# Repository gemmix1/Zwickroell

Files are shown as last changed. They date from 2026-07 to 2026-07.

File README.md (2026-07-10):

# Messstand für Zugproben — Kontakt-Mikrometer (v5)

Autonomes Messgerät für flache **Zugproben (Dogbone, 166 × 20/12 × 6 mm)**:
misst **Dicke und Breite** berührend mit **einem** DC-Motor.

**Prinzip:** Motor + Encoder + T8-Spindel bilden eine Mikrometerschraube
(0,5 µm/Count). Ein federnder **Taststift** mit **Mikroschalter** tastet die
Probe von oben an; ein **Servo** dreht die Probe (0°/90°/180°), ein federnder
**Rastbolzen** definiert die Winkel exakt. Maße entstehen aus Encoder-Differenzen:
`Maß = |2C − (Z_a + Z_b)| · k` — zentrierungs-unempfindlich, einmalige
Endmaß-Kalibrierung. Genauigkeit: **±0,015–0,03 mm** Wiederholbarkeit,
eine Messung ≈ **40 s** (jede Seite 3× angetastet, Mittelwert).

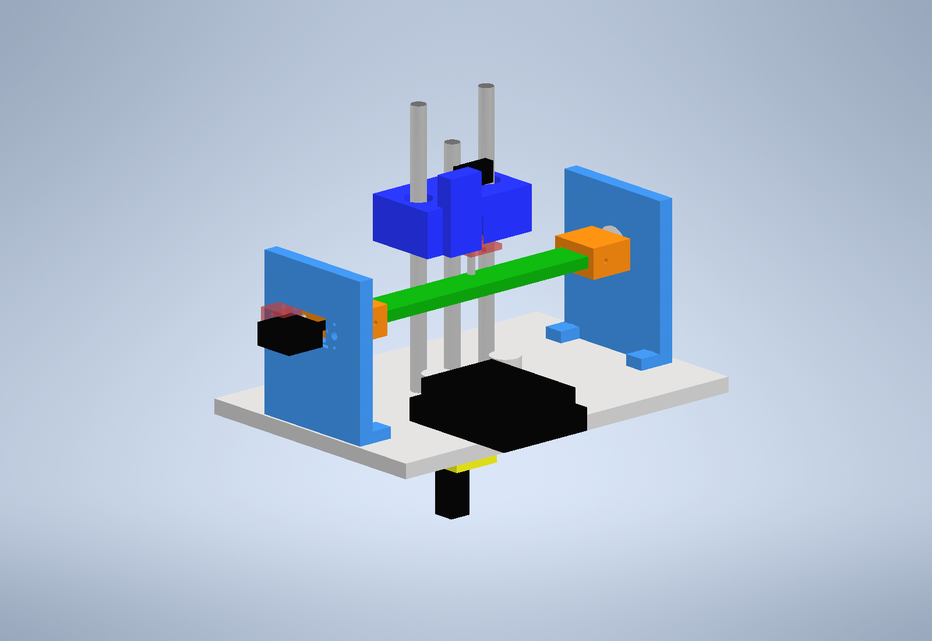
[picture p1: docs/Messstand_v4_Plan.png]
Baugruppe


## 📁 Struktur

| Ordner | Inhalt |
|---|---|
| `cad/` | Inventor-Quellen: **Messstand_v4.iam** (Gesamt-Baugruppe) + alle .ipt |
| `stl/` | **druckfertige STLs** (12 Teile) + Druck-/Montage-Anleitung |
| `gesliced/` | fertig gesliced für **Bambu Lab H2C** (.gcode.3mf, PETG, 0,2 mm) |
| `firmware/` | `messprogramm.ino` (Arduino Uno + Pololu MAX14870-Shield) |
| `scripts/` | PowerShell-Skripte, die alle Teile per Inventor-COM erzeugen |
| `scripts/archiv/` | Skripte früherer Versionen |
| `docs/` | Renderings der Baugruppe |
| `archiv/` | alte Teile/Konzepte (ToF-Variante v3, Sensorarm, …) |

**Anleitungen:** [Bausatz_Anleitung.md](Bausatz_Anleitung.md) (Bestellliste ~78 €,
Verkabelung, Montage, Kalibrierung) · [stl/00_ANLEITUNG.txt](stl/00_ANLEITUNG.txt)
(Druck-Orientierung, Zusammenbau) · [Projektverlauf.md](Projektverlauf.md)
(alle Entscheidungen chronologisch).

## 🔌 Verkabelung (Kurzfassung)

```
Pololu Dual MAX14870 Shield auf Arduino Uno
  M1A/M1B  -> Motor (Waveshare N20 12V 1:150, MIT Encoder!)
  VIN/GND  -> 12 V
Encoder A/B -> Pin 2/3   |  Mikroschalter -> A0/GND
Servo SG90  -> Pin 6     |  (Shield belegt 4,7,8,9,10,12)
```

## ⚙️ Inbetriebnahme

1. `STEIGUNG` in der Firmware an die Spindel anpassen (T8x2 → 2.0) —
   Prüftest: 10 Umdrehungen = 20 mm Weg.
2. `s` — Servo-Positionen justieren, bis der Rastbolzen sauber einrastet.
3. `k` — Dicke kalibrieren (Endmaß bekannter Dicke einspannen).
4. `w` — Breite kalibrieren (Endmaß bekannter Breite, Klemmschrauben angezogen).
5. `m` — messen. `1`–`9` wählt die Zahl der Durchläufe (Standard 1 ≈ 40 s,
   `3` ≈ 2 min für ±15 µm).

## 🖨 Drucken

Alles in `stl/` je 1× (Fensterdeckel 2×), PETG/PLA+, 0,2 mm, 4 Wände, 40 % Infill.
Für den **Bambu Lab H2C** liegen in `gesliced/` fertige Platten
(`Alles_Eine_Platte.gcode.3mf` = alle 13 Teile, ~7,2 h, 331 g — einfach per
USB-Stick an den Drucker). Teile neu erzeugen: `scripts\build_v4b_teile.ps1`
(braucht Autodesk Inventor).

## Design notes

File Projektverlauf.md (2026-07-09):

# Projektverlauf — Messstand für Zugproben

Chronologische Doku der Entscheidungen und Dateien. Stand: 2026-06-16.

## Ziel
Ein Messstand, der eine **flache Zugprobe (Dogbone, 166 × 20/12 × 6 mm)** fest
einspannt und mit einem **Distanzsensor** zwei Maße erfasst: **Breite** und **Dicke**.
Bewegung über **Motor + Encoder + Gewindestangen**, so genau wie möglich.

## Verlauf / Entscheidungen
1. **Motor:** Yunir 1218-N20 (12 V, 27 U/min) — laut Amazon „mit Encoder", real aber
   nur 2 Anschlüsse → **kein Encoder**. Empfehlung: N20 **mit echtem 6-Pin-Encoder**
   (Waveshare, 7 PPR) → mit 4× Quadratur + Getriebe hohe Auflösung.
2. **Antrieb:** Motortreiber **Pololu Dual MAX14870 Shield** (vorhanden).
3. **Lineartechnik:** statt M8-Gewindestange präzisere **T8-Spindel + Anti-Backlash-Mutter**
   empfohlen (Spindelspiel ist der Genauigkeits-Flaschenhals). Reale Vorrichtung nutzt
   nun **2 M8-Gewindestangen als 2 Achsen**.
4. **Messprinzip:** ToF (VL53L1X) ist für 6 mm/12 mm grenzwertig genau (±1 mm). Echte
   Genauigkeit kommt über **Encoder-Position beim Querscan** (Kantenerkennung) bzw.
   einen Laser-Triangulationssensor. Aktuell: Konzept A — **ein Querscan** liefert
   Breite (Kanten) + Dicke (Höhenstufe), 2-Achs-Aufbau für beide Maße.
5. **Einspannung:** Dogbone-Mulde lokalisiert die Probe; **offenes Mess-Fenster** unter
   dem Messbereich erzeugt scharfe ToF-Kanten.

## Dateien
**Mechanik (3D-Druck):**
- `Grundplatte_v2.ipt/.stl` — Platte mit Dogbone-Mulde + ToF-Fenster + Klemmlöcher
- `Sensorarm.ipt/.stl` — M8-angetrieben, abnehmbare Sensorhalterung
- `wellenkupplung_3mm_8mm.ipt/.stl` — Motor (3 mm) ↔ Spindel (8 mm)
- `Gewindestange_M8.ipt`, `Motor_N20.ipt`, `Stuetze.ipt`, `Sensor_VL53L1X.ipt` — Repräsentationsteile
- `Messstand_Komplett.iam` — **Gesamt-Baugruppe** (Positionen sind ein Konzept-Layout, anpassbar)

**Steuerung:**
- `linearantrieb.ino` — Motor + Encoder + ToF (Motor läuft bei Distanz < Schwelle, stoppt sofort)

**Build-Skripte (parametrisch, erzeugen die Teile neu):**
- `build_grundplatte_v2.ps1`, `build_sensorarm.ps1`, `build_kupplung_stl.ps1`,
  `build_einzelteile.ps1`, `build_baugruppe.ps1`
- Inspektions-/Render-Skripte liegen im Ordner `inspect\`

**Eingaben des Nutzers (nicht verändert):** `Grundfläche Neu.ipt`, `12x6_Probestück.ipt`

## Ein-Motor-Ausbau (2026-07-01)
Festgelegt: **nur EIN Motor**, ein einziger Querscan misst Breite UND Dicke.
- `Grundplatte_v3.ipt/.stl` (via `build_grundplatte_v3.ps1`): schmales Fenster
  (scharfe Kanten) + **Referenz-Boss (+5 mm)** neben der Probe für Live-2-Punkt-
  Kalibrierung des ToF. Profil im Scan: Platte(0) | Fenster | Probe | Fenster | Boss(+5).
- `messprogramm/messprogramm.ino` komplett auf Genauigkeit neu geschrieben:
  unidirektionaler Scan (kein Umkehrspiel), interpolierte Kanten (Breite),
  statische 3-Plateau-Nachmessung mit 200 ms-Budget + 2-Punkt-Cal (Dicke),
  N Pässe mit Statistik, Backlash-Anfahrt von unten, EEPROM-Kalibrierung (`z`/`w`).
  Sensor korrekt auf **VL53L0X** (Pololu-Lib aus dem Zip) umgestellt.

## Richtungswechsel v4 — Kontakt-Mikrometer (2026-07-01)
Entscheidung: **berührungslos verworfen**, weil der ToF die Dicke prinzipiell auf
~±0,1 mm begrenzt. Stattdessen **Kontakt-Antastung nach Mikrometer-Prinzip** —
gleichzeitig genauer UND günstiger (Genauigkeit aus Encoder + Mechanik):
- DC-Motor + Encoder + M8-Spindel = Mikrometerschraube (0,298 µm/Count).
- Federgelagerter Taststift + **Mikroschalter** (Probe ist Kunststoff/Composite →
  kein elektrischer Kontakt) meldet Berührung; Encoder liest Position.
- **Servo dreht die Probe** (0/90/180/270°) → dieselbe Achse misst Dicke UND Breite.
- Messung zentrierungs-unempfindlich: `Maß = |2C − (Z_a+Z_b)|·k` (Summe zweier
  gegenüberliegender Antastungen; Drehachse fällt raus). 1× Endmaß-Kalibrierung (`k`).

Entschieden: **vorhandener SG90 (180°)** wird genutzt → `USE_270_SERVO 0`, Breite
über zentrierte Klemme. Wellenlänge 150 mm.

Erzeugt & verifiziert (Volumen-Check + Render):
- `Taster_Schlitten.ipt/.stl` (`build_taster_schlitten.ps1`) — läuft auf 2
  LM8UU-Führungsstangen, M8-Spindelmutter mittig, Taststift + D2F-Mikroschalter vorne.
- `Dreh_Klemme.ipt/.stl` (`build_dreh_klemme.ps1`) — Zentriertasche 20×6 auf der
  Drehachse, SG90-Ritzelaufnahme Ø4.8 + M2 axial, Ø44-Flansch mit 4 Index-Löchern
  (90°) für exakte Rechtwinkligkeit (Index-Pin vom Rahmen).
- `messprogramm.ino` — Kontakt-Mikrometer (Antast-Routine, Servo 0/90/180,
  2C-Kalibrierung im EEPROM).

### Einkaufsliste (Amazon, ~36 € < 50 €) — Servo vorhanden
| Teil | ca. € | Zweck |
|---|---:|---|
| 2× Linearwelle 8 mm glatt (150 mm) | 9 | Führung des Taster-Schlittens (glatt, nicht M8!) |
| 4× LM8UU Linearlager | 7 | Schlitten auf den Wellen |
| Mikroschalter D2F/Subminiatur (5er) | 6 | Kontaktmelder am Taststift |
| Druckfeder-Sortiment | 6 | Taststift-Vorspannung |
| M8-Messing-/POM-Mutter (Anti-Backlash) | 3 | Spindelmutter im Schlitten |
| Härtestift/Kugel 4 mm (Taststift) | 5 | verschleißfeste Tastspitze |
| **Summe** | **~36** | Servo (SG90) + M8-Stange schon vorhanden |

### Baugruppe & restliche Teile (2026-07-01)
Erzeugt: `Rahmen_v4` (Grundplatte + 2 Wellenaufnahmen bei x=−14/y=±22 + Spindelloch
x=−14 + Servo-Wand mit Index-Pin-Loch + Idler-Wand-Journal), `Idler_Klemme`
(Zentriertasche + Ø8-Zapfen), `Fuehrungswelle_8x150`, `Probe_Platzhalter`.
**`Messstand_v4.iam`** = Konzept-Layout aller Teile (Matrix-Platzierung, keine
Constraints) + `Messstand_v4_Konzept.png`. Spindel/Wellen bewusst um 14 mm in X
versetzt, damit die Spindel die Probe (x=0, längs Y) nicht durchdringt; Schlitten
90° gedreht, sodass der Taststift trotzdem über x=0/y=0 (Probenmitte) sitzt.

Druckteile (STL fertig): `Rahmen_v4`, `Taster_Schlitten`, `Dreh_Klemme`, `Idler_Klemme`.
Kaufteil/Referenz (nicht drucken): `Fuehrungswelle_8x150` (glatte Welle), `Probe_Platzhalter`.

## v4b — Design-Review & Komplettkorrektur (2026-07-03)
Systematische Prüfung vor dem Druck fand **schwere Fehler in v4**, alle behoben:
1. **Rahmen_v4 war unbrauchbar**: Wände schwebten 17 mm neben der Platte (Platte
   ±70, Wände bei ±91) → STL aus 3 losen Körpern. UND: Probenspannweite passte
   nicht (Probe ±83, Taschen-Spannweite nur ~100 mm). → Ersetzt durch
   **Grundplatte_v4 (210×140)** + **2 verschraubte Türme** (Maßkette: Taschenboden
   ±83 = Klemme T=∓91, Flansch bis ∓95, Turmwand innen ∓95,5/91,5).
2. **Servo unmontierbar** (keine Löcher, SG90-Welle zu kurz für 8-mm-Wand) →
   Durchsteck-Ausschnitt 24×13 + Flanschvertiefung außen + 2 Schraublöcher.
3. **Motor hing in der Luft** → `Motorblock_N20`: Kupplungskammer Ø22×28,
   Seitenfenster für Madenschrauben, 4×M1.6-Flanschlöcher, 2×M3 an Platte.
4. **Taststift-Mechanik unstimmig** (Kragen Ø9 > Senkung Ø8, Federrichtung falsch,
   Schalter-Tasche passte nicht zur Bauform) → Feder-Pin von UNTEN (Ø13-Senkung,
   Kragen Ø12, `Taststift_Kappe` hält), Pin-Oberende drückt Mikroschalter auf
   Boss oben; Ø4-Stahlstift als Spitze eingeklebt.
5. **Messphysik**: Antasten einer verkippten Fläche = Kantenkontakt → Fehler
   LINEAR im Servo-Winkelfehler (SG90 ±1–2° ≈ ±0,1–0,2 mm — hätte den Taster-
   Vorteil zerstört!). → **Rastbolzen** (`Rast_Halter` + Ø4-Stift + Feder) rastet
   in die 4 Flanschlöcher; Firmware macht `servo.detach()` beim Antasten →
   die Raste definiert den Winkel, nicht der Servo. RETRACT 3→5 mm (Schwenkfreiheit).
6. Kleinkram: Mutterntasche 13,4×15,6 (Ecken!), Spline Ø4,9, Indexlöcher Ø4,2
   (passend zu Ø4-Stiften aus der Bestellung), `limits.h`-Include.
Alle 10 Teile mit Volumen-Check verifiziert; Baugruppe + Renders neu.
Druckordner (`Druckteile_v4\`, Desktop) auf v4b aktualisiert, alte Rahmen-STL entfernt.

## v5 — Präzisions-Upgrade (2026-07-03, Budget 70–80 €)
Budget erhöht → die zwei limitierenden Sparlösungen ersetzt:
- **Spindel: T8-Trapezspindel + Anti-Backlash-POM-Flanschmutter** statt M8-Stange
  (Schlitten: Ø10,5-Durchgang, Ø22,4-Flanschsenkung von unten, 4×M3 auf Ø16-
  Lochkreis bei 45°; Firmware `STEIGUNG` = 2.0 für T8x2 / 8.0 für T8x8).
- **Führung: glatte Ø8-Wellen + LM8UU** statt Gleitbuchsen auf Gewinde
  (Schlitten wieder Ø15-Presssitze; Platte Ø7,8-Presssitze).
- **Idler-Lager: 608ZZ** (8×22×7) im Idler-Turm (Sitz Ø22,3×7,2 von innen,
  Ø18-Lippe außen) statt gedrucktem Gleitloch.
Alle Teile neu generiert + volumen-verifiziert, Druckordner aktualisiert.
Bestellliste v5: ~76–84 € (siehe Bausatz_Anleitung.md).

## Offene Punkte / nächste Schritte
- v5-Teile bestellen (Motor + T8 + Wellen + Lager + Kleinteile) — Deadline Dienstag!
- Nach Motorerhalt: `STEIGUNG` + CPR setzen, Servo-µs justieren (`s`), `k` mit Endmaß.
- Baugruppe ist Layout, keine Constraints — Positionen bei Bedarf feinjustieren.
- Echtes Material in den .ipt zuweisen (aktuell „Generisch").

## (Verworfen) v3 — ToF-Scan
`Grundplatte_v3` + ToF-Firmware bleiben als Referenz im Ordner, sind aber durch v4
ersetzt. Nur relevant, falls doch berührungslos gemessen werden soll.

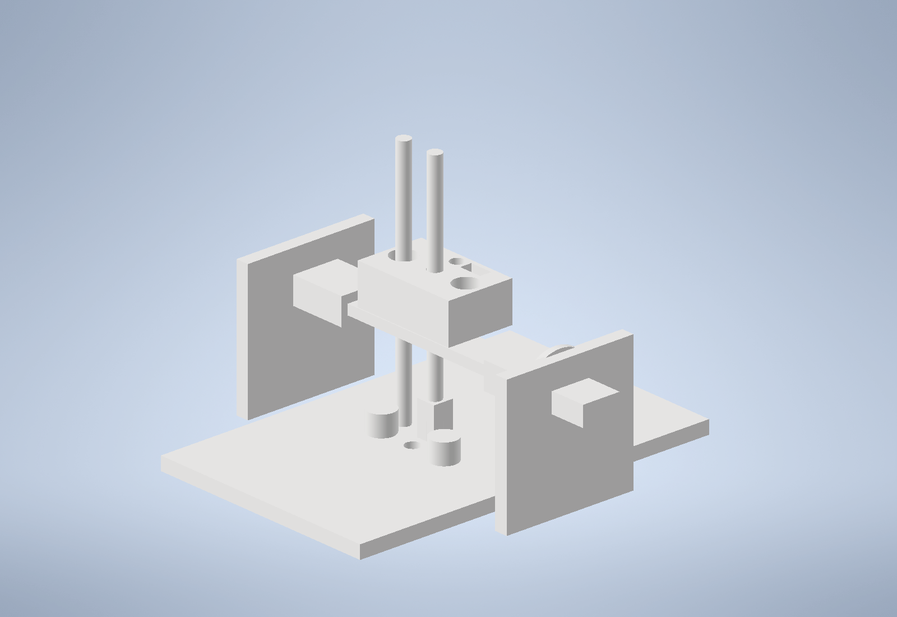
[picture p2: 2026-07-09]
docs/Messstand_v4_Konzept2.png

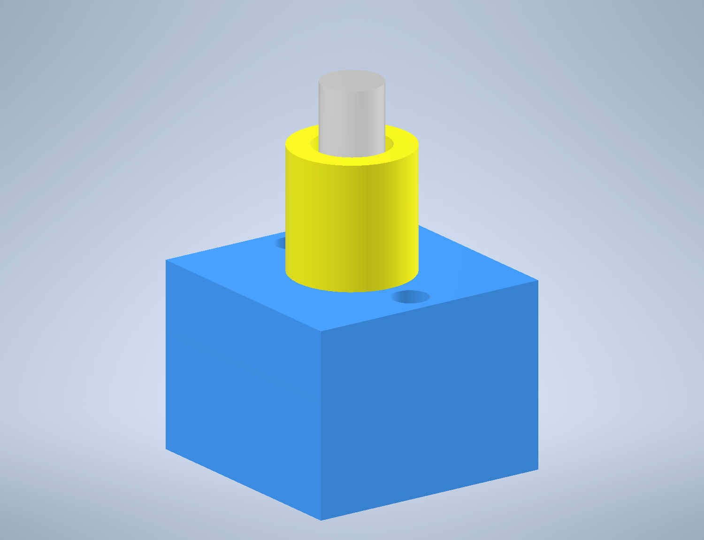
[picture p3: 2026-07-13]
docs/rastbolzen_detail.png

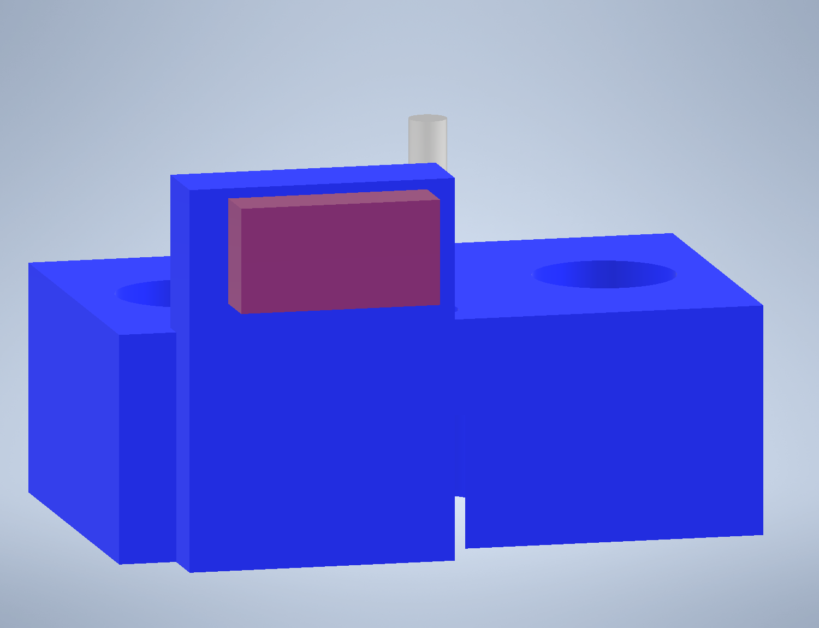
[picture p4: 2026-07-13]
docs/schalter_position.png

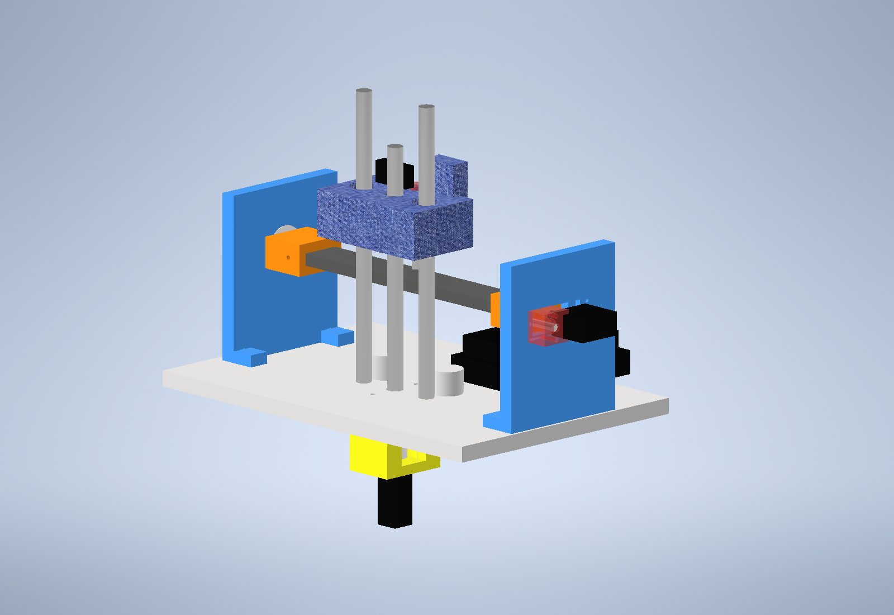
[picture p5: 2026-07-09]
docs/Messstand_v4_Konzept.png

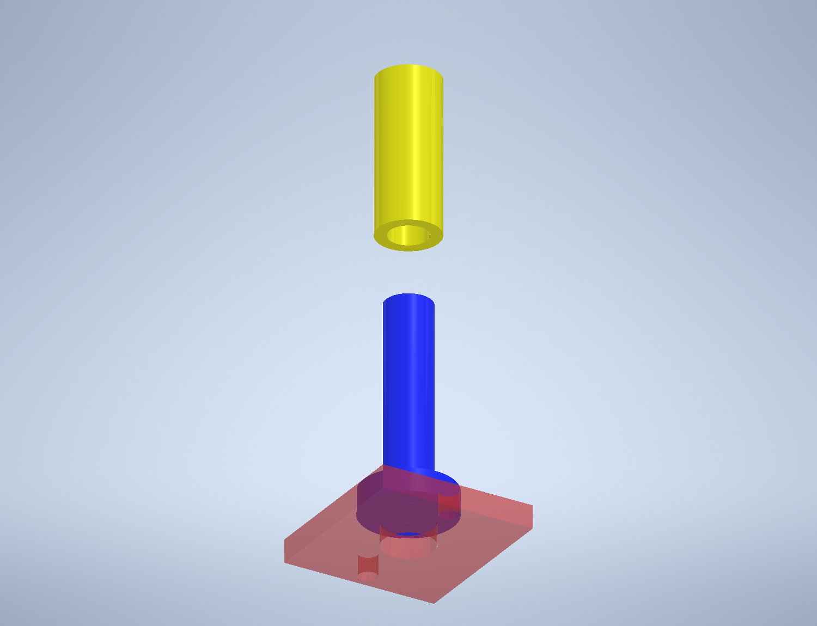
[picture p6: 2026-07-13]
docs/feder_teller_kappe.png

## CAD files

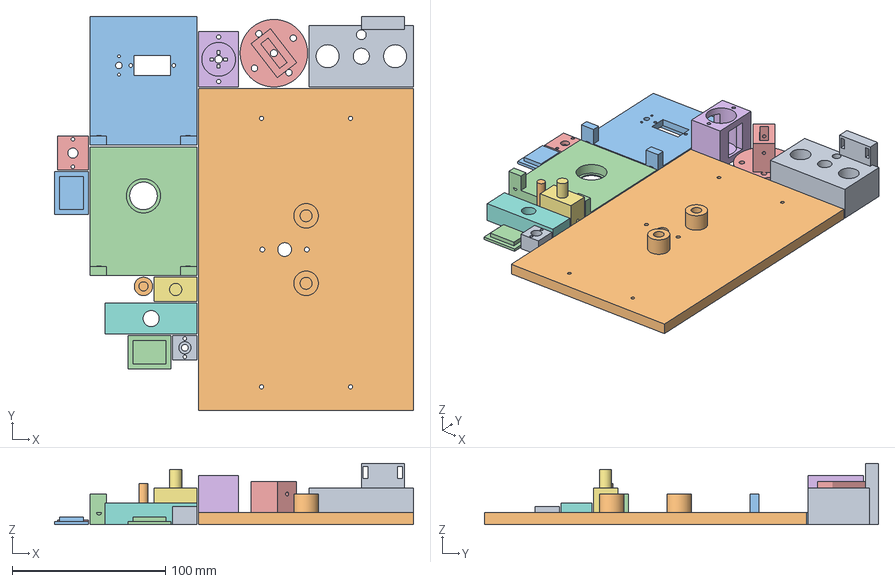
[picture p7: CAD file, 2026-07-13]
gesliced/Alles_Eine_Platte.gcode.3mf
234.0 x 257.0 x 40.0 mm
Taster_Schlitten.stl
Grundplatte_v4.stl
Turm_Servo_flach.stl
Turm_Idler_flach.stl
Dreh_Klemme.stl
Motorblock_N20.stl
Idler_Klemme_flip.stl
Kopf_Bruecke.stl
Rast_Halter.stl
Taststift.stl
Motor_Fensterdeckel.stl
Motor_Fensterdeckel_2.stl
Taststift_Kappe.stl

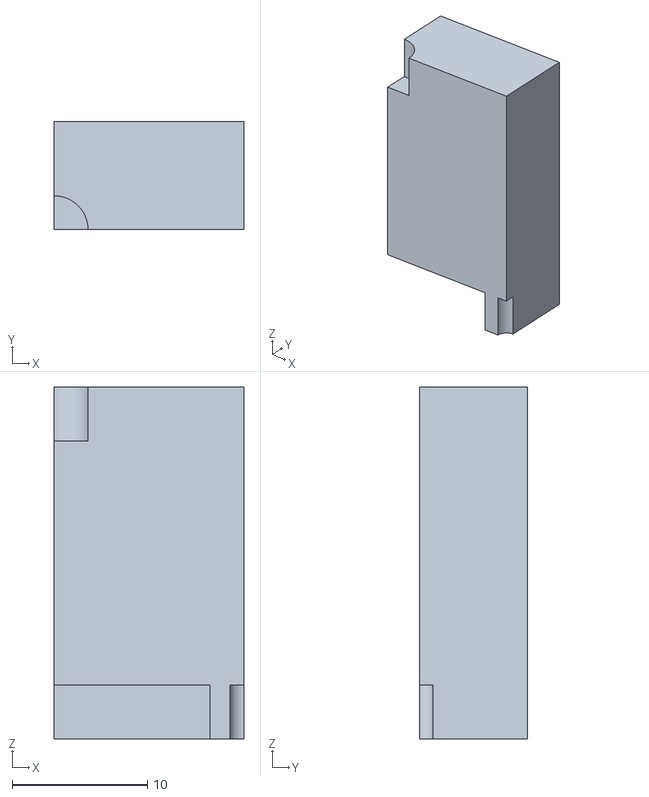
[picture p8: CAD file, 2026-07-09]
Servo_Halterung.stl
14.0 x 8.00 x 26.0

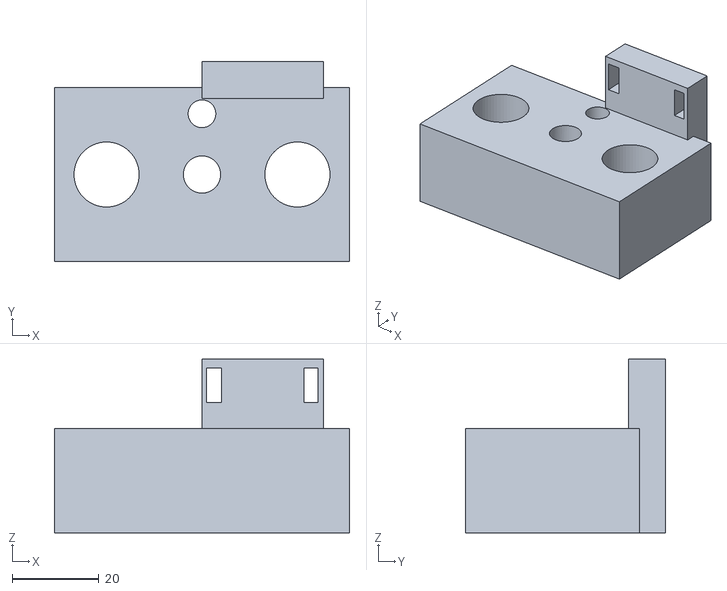
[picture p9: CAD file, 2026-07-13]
stl/Taster_Schlitten_M8.stl
68.0 x 46.0 x 40.0

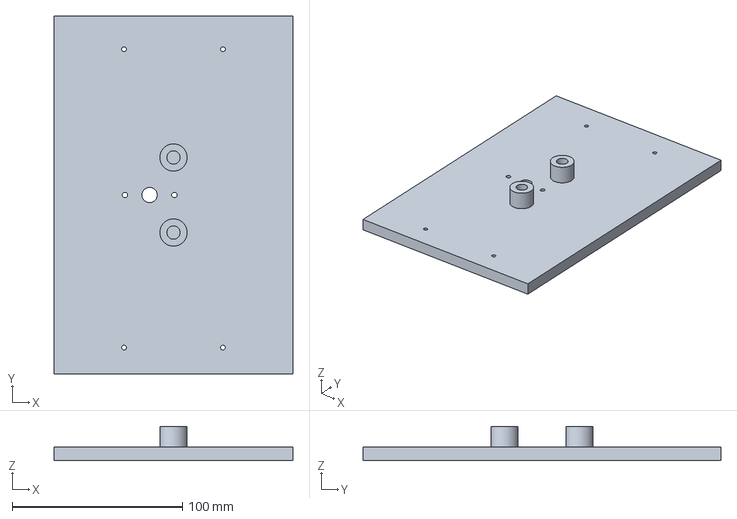
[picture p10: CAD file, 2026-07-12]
gesliced/Platte_1_Grundplatte.gcode.3mf
140.0 x 210.0 x 20.0 mm

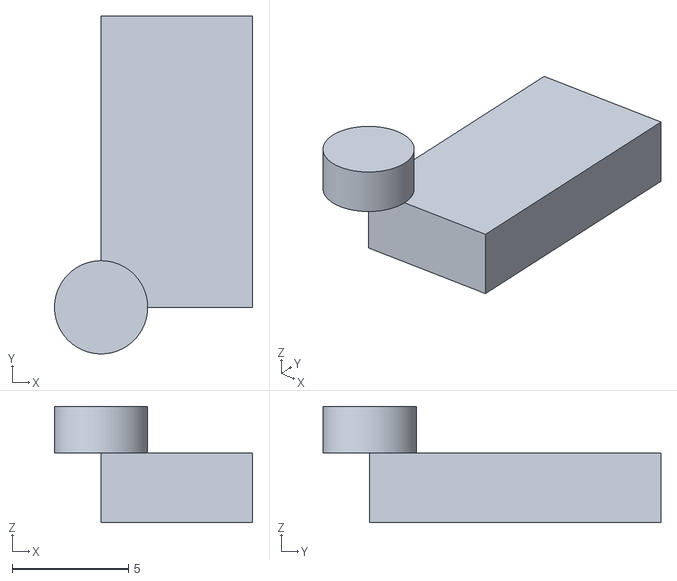
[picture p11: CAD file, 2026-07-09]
Sensor_VL53L1X.stl
8.50 x 14.5 x 5.00

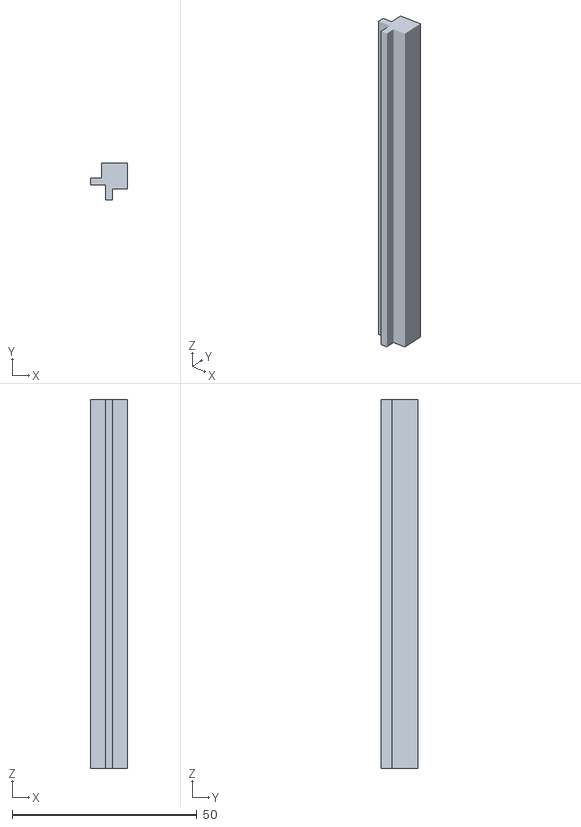
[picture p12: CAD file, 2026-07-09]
Aluprofil_20x20_H100.stl
10.0 x 10.0 x 100.0

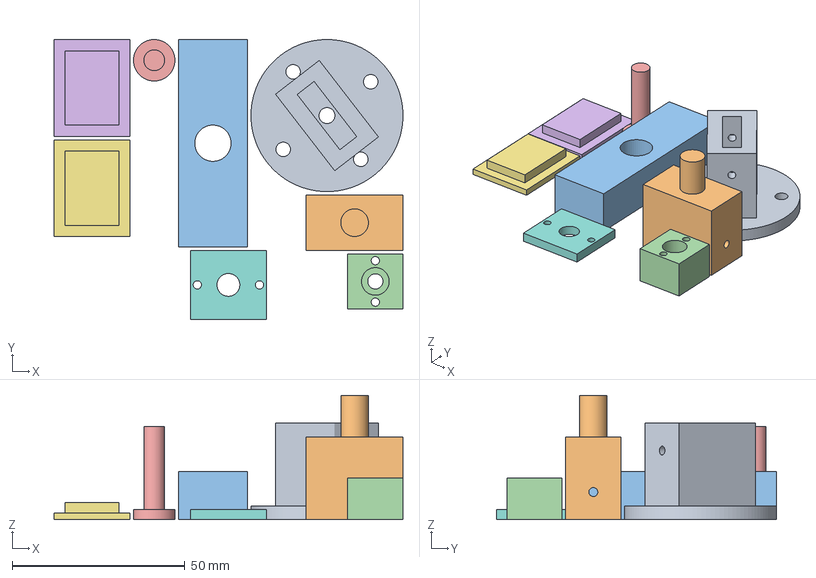
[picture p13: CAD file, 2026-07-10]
gesliced/Platte_4_Kleinteile.gcode.3mf
101.0 x 81.0 x 36.0 mm
Dreh_Klemme.stl
Idler_Klemme_flip.stl
Kopf_Bruecke.stl
Rast_Halter.stl
Taststift.stl
Motor_Fensterdeckel.stl
Motor_Fensterdeckel_2.stl
Taststift_Kappe.stl

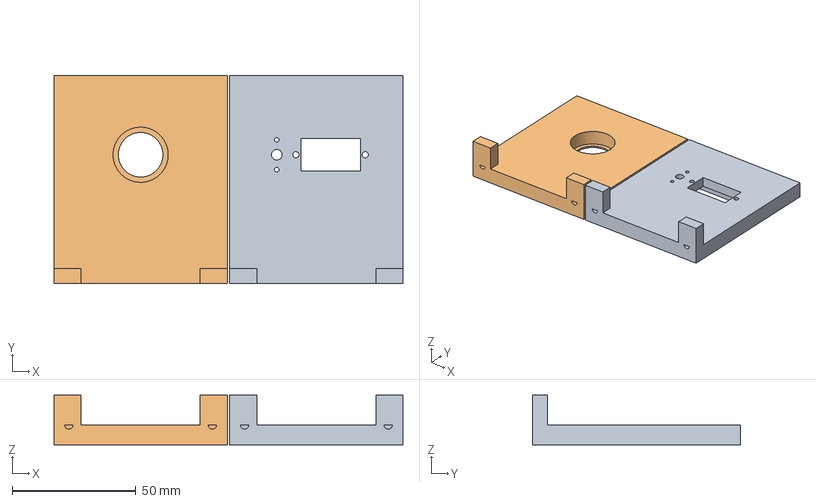
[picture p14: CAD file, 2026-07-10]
gesliced/Platte_2_Tuerme.gcode.3mf
141.0 x 84.0 x 20.0 mm
Turm_Servo_flach.stl
Turm_Idler_flach.stl

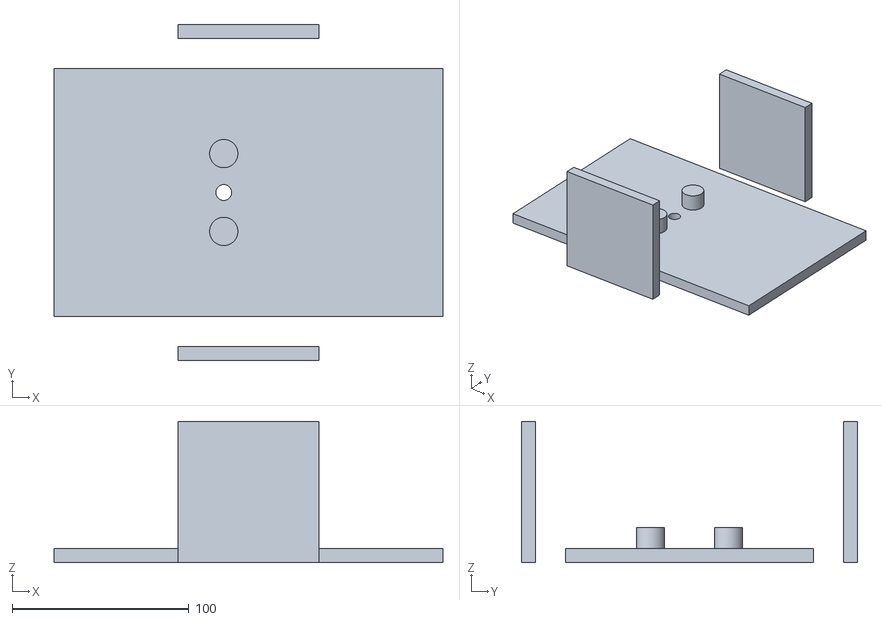
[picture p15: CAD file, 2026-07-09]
Rahmen_v4.stl
220.0 x 190.0 x 80.0

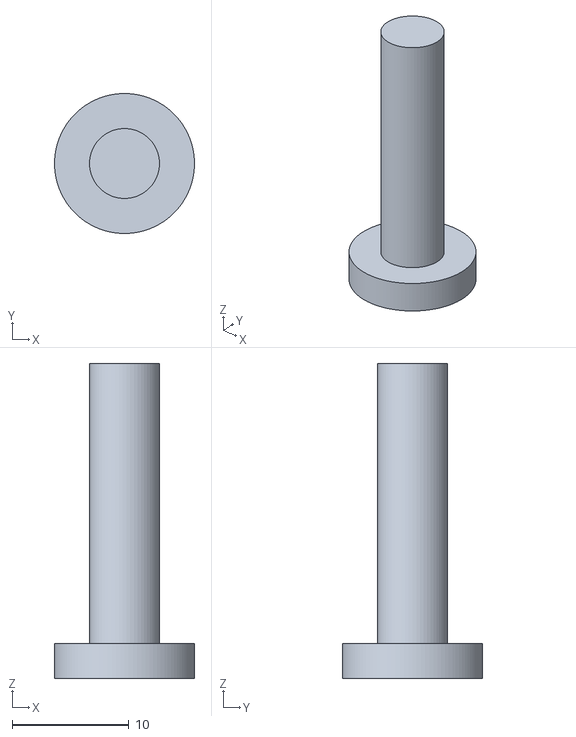
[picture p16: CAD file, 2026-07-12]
stl/Taststift.stl
12.0 x 12.0 x 27.0

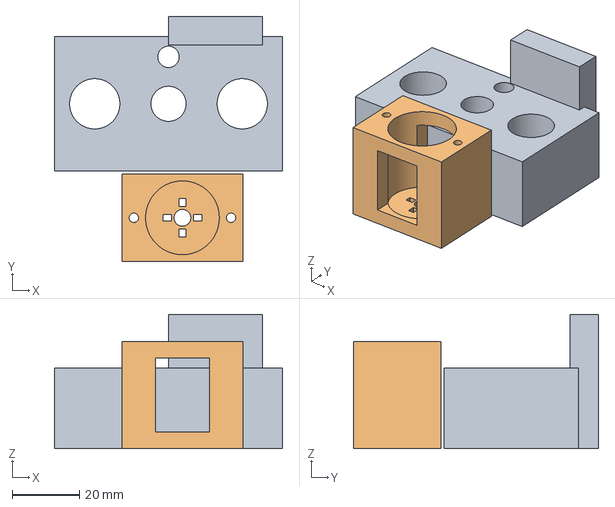
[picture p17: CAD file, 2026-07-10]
gesliced/Platte_3_Schlitten_Motorblock.gcode.3mf
68.0 x 73.0 x 40.0 mm
Taster_Schlitten.stl
Motorblock_N20.stl

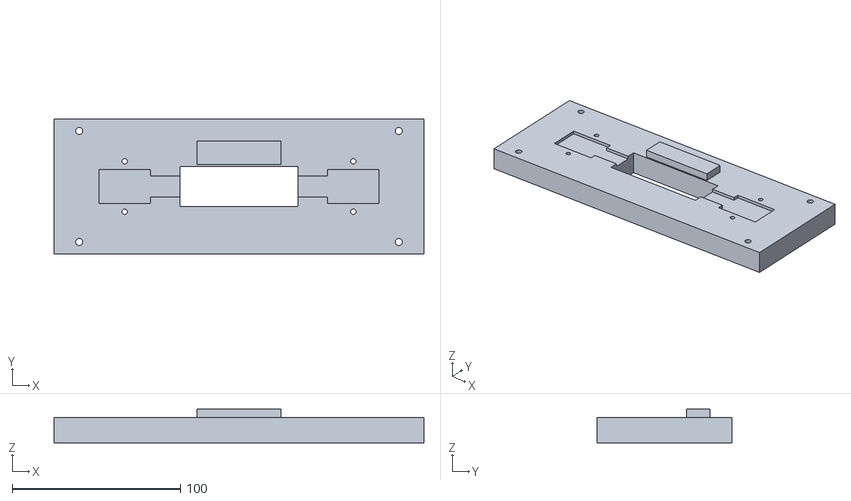
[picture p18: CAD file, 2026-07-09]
Grundplatte_v3.stl
220.0 x 80.0 x 20.0

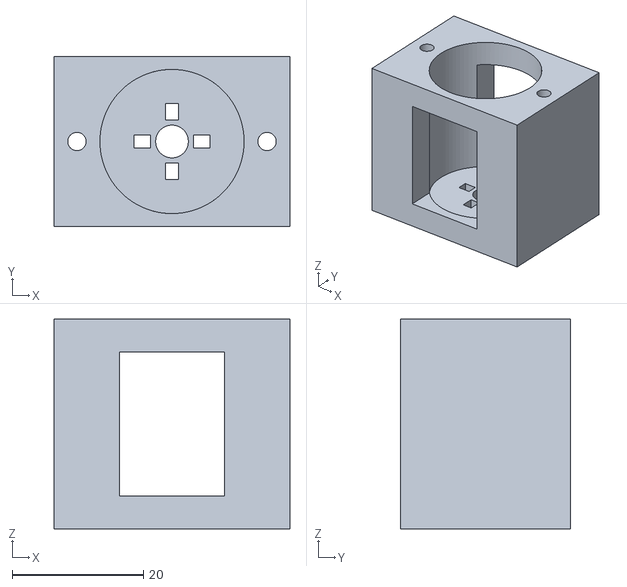
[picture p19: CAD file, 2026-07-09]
stl/Motorblock_N20.stl
36.0 x 26.0 x 32.0

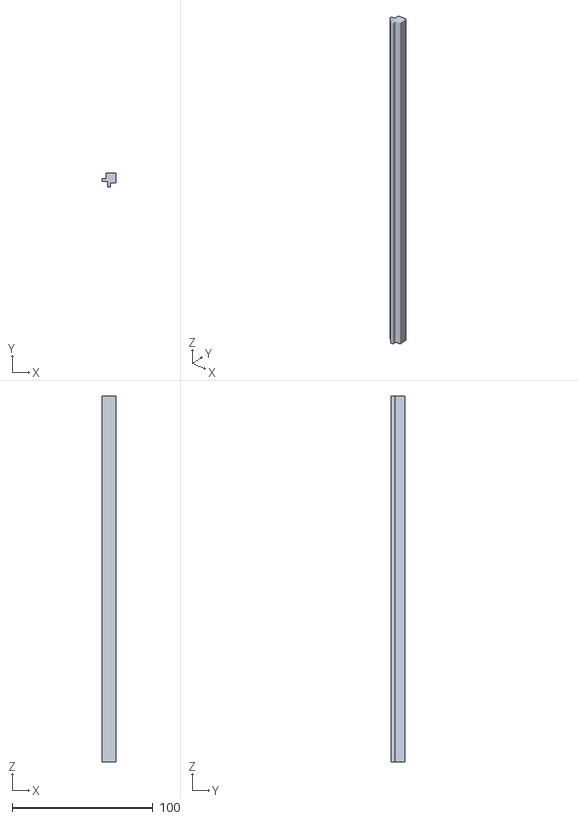
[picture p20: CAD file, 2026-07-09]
Aluprofil_20x20_L260.stl
10.0 x 10.0 x 260.0

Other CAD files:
stl/Taster_Schlitten.stl
stl/Grundplatte_v4.stl
stl/Idler_Klemme.stl
Kupplungsscheibe_v2.stl
12x6_Probestück.stl
Aluprofil_20x20_H100.ipt
Aluprofil_20x20_L180.ipt
Aluprofil_20x20_L180.stl
Aluprofil_20x20_L260.ipt
Aluprofil_20x20_L300.ipt
Aluprofil_20x20_L300.stl
Eckverbinder_20x20.ipt
Eckverbinder_20x20.stl
Feder.ipt
Fuehrungswelle_8x150.stl
Gewindestange_M8.ipt
Gewindestange_M8.stl
Grundplatte_v2.ipt
Grundplatte_v2.stl
Grundplatte_v3.ipt
Kupplungsscheibe.ipt
Kupplungsscheibe.stl
Kupplungsscheibe_v2.ipt
Messstand_Komplett.iam
Motor_N20.ipt
Motor_N20.stl
Motorhalterung.ipt
Motorhalterung.stl
Rahmen_v4.ipt
Sensor_VL53L1X.ipt
Sensorarm_v2.ipt
Sensorarm_v2.stl
Servo_Halterung.ipt
Stuetze.ipt
Stuetze.stl
Stuetze_v2.ipt
Stuetze_v2.stl
archiv/12x6_Probestück.stl
archiv/Aluprofil_20x20_H100.ipt
archiv/Aluprofil_20x20_L180.ipt
archiv/Aluprofil_20x20_L180.stl
archiv/Aluprofil_20x20_L260.ipt
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

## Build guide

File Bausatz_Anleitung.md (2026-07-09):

# Bausatz – Messstand v4 (autonom, Kontakt-Taster)

Komplettpaket: bestellen → drucken → verdrahten → montieren → kalibrieren.

## 1) Bestellliste v5 (Amazon.de, ~76–84 €, Budget 70–80)

Präzisions-Aufbau: echte Linearführung + spielfreie Spindel + Kugellager.

| Teil | ~€ | Amazon.de |
|---|---:|---|
| **Encoder-Motor Waveshare N20 — 12V / 1:150 wählen!** | 15 | B0CW1TCCTL (kritisch: MIT Encoder, 6 Kabel) |
| **T8-Trapezspindel 200 mm + Anti-Backlash-POM-Mutter** (T8x2 bevorzugt, T8x8 ok) | 13 | Suche „T8 Spindel 200mm Anti Backlash" |
| **2× Linearwelle Ø8 × 150 mm glatt** (nicht Gewinde!) | 7 | Suche „linearwelle 8mm 150" |
| **LM8UU Linearlager** (12er, brauchst 2) | 8 | B08Y6LZQZ1 |
| **608ZZ Kugellager** 8×22×7 (10er, brauchst 1) | 5 | Suche „608ZZ Kugellager" |
| **Metallkupplung 3→8 mm** (2er) | 7 | B08G555R9Y |
| Mikroschalter Hebel SPDT (10er, brauchst 1) | 7 | B08736V215 |
| Druckfeder-Sortiment (brauchst 2: Taster + Rastbolzen) | 7 | B0GDFK7CX8 |
| Zylinderstift 4 mm gehärtet (brauchst 2: Tastspitze + Raststift) | 7 | B09JJXLM1Z |
| *falls nicht da:* Schrauben-Sortiment M2/M2.5/M3 (+M1.6) | 8 | Suche „Schrauben Sortiment" |

**Summe: 76 € (84 € mit Schrauben-Set).** Vorhanden: SG90, Arduino,
MAX14870-Shield, 12-V-Netzteil. Deine M8-Gewindestangen werden nicht mehr
gebraucht (T8 ersetzt die Spindel — spielfrei und gerade).
Motor-Seite: **12 V** und **1:150 (200 RPM)** auswählen, sonst stimmt CPR nicht.
**Firmware:** `STEIGUNG` auf die Spindel setzen (T8x2 → 2.0, T8x8 → 8.0).

**Hast du schon:** Servo SG90, Arduino Uno, Pololu Dual MAX14870 Shield, M8-Gewindestange (= Spindel), 12 V Netzteil.
**Nicht mehr nötig:** ToF (nur bei der ungenauen Variante).

## 2) Drucken — v4b (KORRIGIERTER SATZ, 10 Teile)
Siehe `Druckteile_v4\00_ANLEITUNG.txt`. PETG/PLA+, 4 Wände, 0,15–0,2 mm.
**Alte `Rahmen_v4.stl` NICHT drucken** (Konstruktionsfehler, ersetzt durch
Grundplatte_v4 + 2 verschraubte Türme).

| Teil | Zweck |
|---|---|
| Grundplatte_v4 (210×140, Bett ≥210!) | Basis mit Wellen-Bossen, allen Schraublöchern |
| Turm_Servo / Turm_Idler | Endwände, verschraubt (druckbett-freundlich) |
| Motorblock_N20 | hält Motor + Kupplungskammer mit Zugangsfenstern |
| Taster_Schlitten | Mikrometer-Schlitten (Feder-Pin von unten, Schalter-Boss oben) |
| Dreh_Klemme / Idler_Klemme | Probenaufnahme (Tasche 16 tief) |
| Taststift + Taststift_Kappe | federnder Taster (Ø4-Stahlstift als Spitze einkleben) |
| Rast_Halter | federnder **Rastbolzen** → exakte 0/90/180° (Genauigkeits-Kernstück!) |

Zusätzlich nötig: Schrauben-Sortiment M1.6/M2/M2.5/M3 (falls nicht vorhanden, ~8 €).
Zuerst 20-mm-Testwürfel → Passungen prüfen (Ø15, Ø8, M8-Mutter, Ø4-Stifte).

## 3) Verdrahtung

Shield auf den Arduino Uno stecken. Dann:

| Von | Nach |
|-----|---|
| Motor (2 dicke Leitungen) | M1A / M1B (Shield) |
| Encoder A | Pin 2 |
| Encoder B | Pin 3 |
| Encoder VCC / GND | 5V / GND |
| Mikroschalter COM | GND |
| Mikroschalter NO | A0 |
| Servo Signal / VCC / GND | Pin 6 / 5V / GND |
| 12 V Netzteil + / − | Shield VIN / GND |

Shield belegt Pin 4,7,8,9,10,12 → keine Kollision. Frei genutzt: 2,3 (Encoder), 6 (Servo), A0 (Schalter).
Wenn der Servo den Arduino „browned out" (Reset beim Drehen): Servo-5V aus separatem 5 V-Regler/BEC speisen, **GND gemeinsam**.

## 4) Montage-Reihenfolge

1. **Schlitten:** 2× LM8UU in `Taster_Schlitten` pressen, M8-Mutter in die Tasche, Taststift Ø4 + Feder in die vordere Bohrung, Mikroschalter davor schrauben (Stift drückt bei Kontakt auf den Hebel).
2. **Rahmen:** 2 glatte Ø8-Wellen senkrecht in die Bosse pressen. M8-Gewindestange (Spindel) mittig einsetzen.
3. **Antrieb:** Motor unter die Platte, Welle durch das Spindelloch, mit der Kupplung an die M8-Stange. Motor fixieren.
4. **Schlitten auf** die 2 Wellen (LM8UU) + M8-Mutter auf die Spindel fädeln.
5. **Servo** an die Servo-Wand (−Y), `Dreh_Klemme` auf das SG90-Ritzel. `Idler_Klemme`-Zapfen in das Journal der anderen Wand.
6. **Index-Pin** durch das Wand-Loch in eines der 4 Flansch-Löcher → definiert exakt 0/90/180°.
7. **Probe** mit beiden Grip-Enden in die zwei Klemmen (Zentriertaschen) stecken.

## 5) Kalibrieren (in dieser Reihenfolge)

1. **CPR setzen:** aus dem Motor-Datenblatt `CPR = PPR × 4 × 150`. Falls unklar → **counts/mm messen** (Spindel bekannte Strecke fahren, Ticks zählen) und `MM_PRO_COUNT` direkt setzen. *(Wichtig für die Skala!)*
2. **Servo-Winkel:** `s` senden → SG90 fährt 0/90/180. `SERVO_0/90/180` (µs) so anpassen, dass der Index-Pin sauber in die Löcher fällt (Rechtwinkligkeit!).
3. **Vorzeichen:** einmal `m`; kommt Dicke negativ → `DIM_SIGN = -1`.
4. **Nullen:** Endmaß bekannter Dicke einspannen → `k`. Setzt `2C` (EEPROM).
5. **Messen:** `m` → Dicke + Breite als Mittelwert ± Standardabweichung.

`?` = Hilfe/aktuelle Werte · `t` = Antasten testen.

## Zeitplan bis Dienstag
- **Heute:** Motor + Kleinteile bestellen (Prime), 4 Teile drucken.
- **Sa/So:** Montage + Verdrahtung.
- **Mo:** Servo-Winkel + Kalibrierung, Messungen.

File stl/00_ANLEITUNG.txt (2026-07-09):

MESSSTAND v4b - AUTONOM (Kontakt-Taster, Servo dreht Probe, Rastbolzen)
=======================================================================
KORRIGIERTE VERSION - alte Rahmen_v4.stl NICHT mehr drucken!
Alle 10 STLs je 1x drucken (+ Kupplung optional, besser Metall kaufen).

DRUCKEN
-------
Material : PETG oder PLA+ | Schicht 0,15-0,2 mm | 4 Waende | 40-50 % Infill

Teil                     Orientierung / Hinweis
Grundplatte_v4           flach aufs Bett. ACHTUNG: 210 x 140 mm -> Bett >= 210
                         noetig (Ender 3 / Prusa: passt). Zu klein? Melden,
                         dann teile ich die Platte.
Turm_Servo               flach auf die grosse Wandflaeche legen
Turm_Idler               flach auf die grosse Wandflaeche legen
Motorblock_N20           stehend wie modelliert (Kammer nach oben)
Taster_Schlitten         stehend (LM8UU-Bohrungen SENKRECHT)
                         -> Variante fuer T8-Spindel (Flanschmutter). NUR EINE
                            der beiden Schlitten-Varianten drucken!
Taster_Schlitten_M8      ALTERNATIVE: fuer normale M8-Gewindestange als
                         Spindel (Sechskantmutter-Tasche). Firmware:
                         STEIGUNG = 1.0 (M8x1) / 1.25 (M8 normal) setzen!
                         Mit T8-Spindel: STEIGUNG = 2.0.
Dreh_Klemme              Flansch nach unten
Idler_Klemme             Zapfen nach unten, mit Brim
Taststift                stehend (Kragen unten), langsam drucken
Taststift_Kappe          flach
Rast_Halter              flach (Federtasche oben)

v5-PRAEZISIONS-AUFBAU (Budget-Upgrade):
- Fuehrung: 2x LM8UU-Kugellager in die Ø15-Bohrungen des Schlittens pressen,
  laufen auf 2 GLATTEN Ø8-Wellen (Presssitz in Ø7,8-Bohrungen der Platte, +Kleber).
- Spindel: T8-TRAPEZSPINDEL mit Anti-Backlash-POM-Flanschmutter. Mutter von
  UNTEN in die Ø22,4-Senkung des Schlittens, 4x M3 auf dem Ø16-Lochkreis.
  In der Firmware STEIGUNG setzen: T8x2 -> 2.0, T8x8 -> 8.0!
- Idler-Lager: 608ZZ-Kugellager (8x22x7) von INNEN in den Idler-Turm pressen
  (Lippe aussen haelt), Ø8-Zapfen der Idler-Klemme steckt im Lager.
Passungen pruefen: Ø15 (LM8UU), Ø22,3 (608ZZ), Ø8 (Wellen/Zapfen), Ø4-Stifte.
Bei zu eng: aufbohren/feilen oder Toleranz im build-Skript aendern.

SO FUNKTIONIERT DIE MECHANIK (Zusammenbau-Logik)
------------------------------------------------
1. TASTSTIFT: Ø4-Stahlstift (aus 24er-Pack) in die Aufnahme unten am
   gedruckten Taststift kleben = verschleissfeste Spitze.
   Stift von UNTEN in den Schlitten: Feder (OD ~9-11 mm) in die Ø13-Senkung,
   Kragen drueckt dagegen, Kappe mit 2x M2 von unten anschrauben.
   Stift-Oberende schaut oben ~3 mm raus -> drueckt beim Kontakt den
   MIKROSCHALTER (V-153): am Boss mit 2x M3 + Muttern durch die
   LANGLOECHER befestigen — Hoehe so einstellen, dass der Hebel das
   Stift-Ende bei ~1-2 mm Anhub ausloest (Langloecher = Justage!).
2. RASTBOLZEN (wichtig fuer Genauigkeit!): zweiter Ø4-Stahlstift in den
   Rast_Halter (aussen am Servo-Turm, 2x M2.2), Feder dahinter, Tesa drueber.
   Der Stift rastet in die 4 Flansch-Loecher der Dreh_Klemme -> exakte
   0/90/180-Grad-Winkel. Die Firmware schaltet den Servo beim Antasten ab
   (detach), damit die Raste den Winkel definiert - NICHT der Servo.
3. SERVO: SG90 von aussen durch den Turm-Ausschnitt stecken, Flansch liegt
   in der Vertiefung, 2 Schrauben. Welle greift in die Dreh_Klemme (Ø4.9),
   M2-Schraube axial durch die Klemme in die Servowelle.
4. MOTOR: N20 von unten an den Motorblock schrauben (M1.6, 4 Loecher passen
   fuer gaengige Muster), Kupplung in der Kammer, Madenschrauben durch die
   Seitenfenster anziehen. Block mit 2x M3 von oben durch die Platte.
5. TUERME: je 2x M3 durch die Fusslaschen in die Platten-Pilotloecher.
6. PROBE einlegen: erst in die Dreh_Klemme-Tasche (16 mm tief), dann
   Idler_Klemme aufs andere Ende, Idler-Turm ueber den Zapfen schieben,
   Turm festschrauben.
7. KLEMMSCHRAUBEN (M3 quer in beiden Klemmen) sanft anziehen: druecken das
   Probenende immer gegen DIESELBE Taschenwand -> konstanter Versatz, der
   per 'w'-Kalibrierung komplett rausfaellt (wichtig fuer die BREITE!).

NICHT DRUCKEN - KAUFEN (siehe Bausatz_Anleitung.md, v5 ~76-84 EUR)
------------------------------------------------------------------
Encoder-Motor N20 12V 1:150 (6-Pin!), T8-Spindel+Anti-Backlash-Mutter,
2x Ø8-Welle 150 glatt, LM8UU, 608ZZ, Metallkupplung 3->8, Mikroschalter,
Federn, Ø4-Zylinderstifte, Schrauben M1.6/M2/M2.5/M3.

FIRMWARE: messprogramm/messprogramm.ino
  Encoder A/B->Pin2/3, Schalter->A0/GND, Servo->Pin6, Motor->M1, 12V->VIN
  Kalibrieren: 'k' (Dicken-Endmass) -> 'w' (Breiten-Endmass, Klemmschrauben
  wie im Messbetrieb!) -> 'm' = messen. Details: Bausatz_Anleitung.md
Baugruppe/3D-Plan: Messstand_v4.iam (Inventor)

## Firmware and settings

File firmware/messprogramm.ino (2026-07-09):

// ============================================================
//  Messprogramm v4 — Kontakt-Mikrometer, EIN DC-Motor + Servo
//  ------------------------------------------------------------
//  Prinzip: DC-Motor + Encoder + M8-Spindel = Mikrometerschraube
//           (1.25 mm / 4200 Counts = 0.298 um/Count).
//           Federgelagerter Taststift + MIKROSCHALTER taste't die
//           Probe von oben an; Encoder liest die Kontaktposition.
//           SERVO dreht die Probe -> dieselbe Achse misst Dicke UND Breite.
//
//  Messung (zentrierungs-unempfindlich, Sum-of-two-touches):
//     Dicke  t = |2C - (Z0   + Z180)| * k
//     Breite w = |2C - (Z90  + Z270)| * k        (270-Grad-Servo)
//  2C wird EINMAL mit einem Endmass bekannter Dicke kalibriert ('k').
//
//  180-Grad-Servo (z.B. SG90): kein 270 moeglich -> Breite ueber
//     zentrierte Probe: w = |2C - 2*Z90| * k  (USE_270_SERVO = 0).
//
//  Serielle Befehle:
//     m -> messen (N Paesse) -> DICKE/BREITE als Mittelwert +/- Stdabw.
//     k -> 2C kalibrieren: Endmass (KNOWN_GAUGE) einspannen, 'k' senden
//     t -> Einzel-Antastung testen (Debug)
//     s -> Servo die 4 (bzw. 3) Positionen abfahren (Justage/Detent)
//     ? -> Hilfe / Kalibrierwert
// ============================================================

#include <Servo.h>
#include <EEPROM.h>
#include <limits.h>
#include "DualMAX14870MotorShield.h"

DualMAX14870MotorShield motoren;
Servo dreher;

// ---------- PINS ----------
const int encoderA = 2;    // Interrupt
const int encoderB = 3;    // Interrupt
const int TASTER    = A0;  // Mikroschalter -> GND (INPUT_PULLUP, LOW = Kontakt)
const int SERVO_PIN = 6;   // frei (Shield belegt 4,7,8,9,10,12)

// ---------- KONFIG ----------
#define USE_270_SERVO 0    // 0 = SG90 180-Grad (Breite ueber zentrierte Klemme)

// ---------- MECHANIK / ENCODER ----------
const long   CPR          = 4200;              // 7 PPR x 4 x 150
// ============================================================================
// SPINDELSTEIGUNG mm/Umdrehung — MUSS zur eingebauten Spindel passen,
// sonst sind ALLE Masse um diesen Faktor falsch!
//   1.0  = deine M8-Feingewinde-Stange (M8x1)
//   1.25 = normale M8-Gewindestange (Standard-Steigung! pruefen!)
//   2.0  = bestellte T8x2-Trapezspindel  |  8.0 = T8x8
// PRUEFTEST: Spindel exakt 10 Umdrehungen drehen und Weg messen:
//   10 mm -> 1.0 | 12,5 mm -> 1.25 | 20 mm -> 2.0
// ============================================================================
const float  STEIGUNG     = 2.0;               // = bestellte T8x2 (1mm-Spindeln
                                               //   liefern erst im August!)
const float  MM_PRO_COUNT = STEIGUNG / CPR;    // bei 2.0: ~0.00048 mm/Count
const int    DIM_SIGN     = +1;                // falls Mass negativ: auf -1 setzen

// ---------- ANTASTEN ----------
const int    SPEED_FAST   = 250;               // schnelle Anfahrt (Feder puffert 11mm)
const int    SPEED_SLOW   = 45;                // langsame Feinantastung (bleibt!)
const long   BACKOFF      = (long)(0.5 / MM_PRO_COUNT);  // Rueckzug vor Feinantastung
const long   RETRACT      = (long)(5.0 / MM_PRO_COUNT);  // VOR DEM DREHEN: Probe muss
                                                          // frei schwenken (>=5mm)!
const long   RETRACT_KURZ = (long)(1.0 / MM_PRO_COUNT);  // zwischen Antastungen
                                                          // derselben Seite (spart Zeit)
const long   MAX_TRAVEL   = (long)(25.0/ MM_PRO_COUNT);  // Sicherheits-Grenze
// MESSVORGABE: jede Seite wird 3x angetastet, verwendet wird der MITTELWERT.
const int    N_TOUCH      = 3;
// Durchlaeufe des Gesamtablaufs (im Serial Monitor mit '1'..'9' einstellbar).
// Standard 1 -> Gesamtmessung ~40 s. Jeder weitere Durchlauf rastet den
// Winkel NEU ein und verbessert den Mittelwert mit 1/sqrt(n)
// (z.B. '3' fuer Praezisionsmessung ~2 min).
int          nPasses      = 1;
const int    MAX_PASSES   = 9;

// ---------- SERVO-POSITIONEN (us) — SG90 180-Grad, an Detent justieren ----------
const int    SERVO_0   = 500;    // 0 Grad
const int    SERVO_90  = 1450;   // 90 Grad (SG90 ~500..2400 us)
const int    SERVO_180 = 2400;   // 180 Grad
const int    SERVO_270 = 2400;   // (bei SG90 ungenutzt)
const int    SERVO_SETTLE = 400;               // ms Beruhigung nach Drehung

// ---------- KALIBRIER-ENDMASSE ----------
const float  KNOWN_GAUGE  = 6.000;             // wahre Dicke  des Dicken-Endmasses  ('k')
const float  KNOWN_BREITE = 12.000;            // wahre Breite des Breiten-Endmasses ('w')

// ---------- EEPROM ----------
const int    EE_MAGIC_ADDR = 0;  const byte EE_MAGIC = 0x6D;
const int    EE_2C_ADDR    = 1;  // long (Counts)
const int    EE_BOFF_ADDR  = 5;  // float (mm)
long  twoC = 0;                   // Kalibrier-Konstante (Counts), via 'k'
float breiteOff = 0.0;            // Breiten-Offset (mm), via 'w' — kompensiert den
                                  // konstanten Klemm-Versatz (Klemmschraube!)

// ---------- ENCODER ----------
volatile long pulseCount = 0;
volatile uint8_t letzterZustand = 0;
const int8_t QUAD[16] = { 0,-1,1,0, 1,0,0,-1, -1,0,0,1, 0,1,-1,0 };
void encoderUpdate() {
  uint8_t a=digitalRead(encoderA), b=digitalRead(encoderB);
  uint8_t z=(a<<1)|b;
  pulseCount += QUAD[((letzterZustand<<2)|z) & 0x0F];
  letzterZustand=z;
}
long pos() { long c; noInterrupts(); c=pulseCount; interrupts(); return c; }

bool kontakt() { return digitalRead(TASTER)==LOW; }
void stop()    { motoren.setM1Speed(0); }

// ---------- Spindel um dCounts fahren (Vorzeichen = Richtung) ----------
void fahre(long dCounts, int speed) {
  long ziel = pos() + dCounts;
  if (dCounts >= 0) { motoren.setM1Speed(abs(speed));  while (pos() < ziel) {} }
  else              { motoren.setM1Speed(-abs(speed)); while (pos() > ziel) {} }
  stop();
}

// ---------- EINE Antastung: nach unten bis Kontakt, Position zurueck ----------
// Rueckgabe: Encoder-Count bei Kontakt. Immer aus derselben Richtung -> Backlash konsistent.
// Konvention: +SPEED bewegt den Taster RICHTUNG Probe.
long tasteEinmal(long rueckzug) {
  long start = pos();
  // 1) schnelle Anfahrt bis Grobkontakt
  motoren.setM1Speed(SPEED_FAST);
  while (!kontakt() && (pos()-start) < MAX_TRAVEL) {}
  stop();
  if (!kontakt()) { return LONG_MIN; }          // nichts getroffen
  // 2) zurueck und langsam final antasten (praezise, kraftarm)
  fahre(-BACKOFF, SPEED_FAST);
  motoren.setM1Speed(SPEED_SLOW);
  while (!kontakt() && (pos()) < start+MAX_TRAVEL) {}
  long p = pos();
  stop();
  // 3) freifahren
  fahre(-rueckzug, SPEED_FAST);
  return p;
}

// N Antastungen mitteln: zwischendurch nur kurz abheben, erst nach der
// letzten Antastung voll freifahren (Schwenkfreiheit fuers Drehen)
long tasteGemittelt(bool &ok) {
  long summe=0; int n=0;
  for (int i=0;i<N_TOUCH;i++){
    long rz = (i==N_TOUCH-1) ? RETRACT : RETRACT_KURZ;
    long p=tasteEinmal(rz); if(p!=LONG_MIN){summe+=p; n++;}
  }
  ok = (n>0); return ok ? summe/n : 0;
}

// Servo bewegen; fuer die Antastung wird der Servo ABGESCHALTET (detach):
// der federnde RASTBOLZEN zieht den Klemmen-Flansch exakt ins 0/90/180-Loch.
// (Servo-Winkelfehler geht sonst LINEAR in das Mass ein - Kantenkontakt!)
void servoZu(int us) {
  if (!dreher.attached()) dreher.attach(SERVO_PIN);
  dreher.writeMicroseconds(us);
  delay(SERVO_SETTLE);
}
long messePos(int us, bool &ok) {
  servoZu(us);
  dreher.detach();            // schlaff -> Rastbolzen definiert den Winkel
  delay(250);
  return tasteGemittelt(ok);
}

// ---------- EIN PASS: Dicke + Breite ----------
bool einPass(float &dicke, float &breite) {
  bool o1,o2,o3,o4;
  long z0   = messePos(SERVO_0,   o1);
  long z180 = messePos(SERVO_180, o2);
#if USE_270_SERVO
  long z90  = messePos(SERVO_90,  o3);
  long z270 = messePos(SERVO_270, o4);
  if(!(o1&&o2&&o3&&o4)) return false;
  long rawT = z0 + z180;
  long rawW = z90 + z270;
  dicke  = DIM_SIGN * (twoC - rawT) * MM_PRO_COUNT;
  breite = DIM_SIGN * (twoC - rawW) * MM_PRO_COUNT;
#else
  long z90  = messePos(SERVO_90,  o3); o4=true;
  if(!(o1&&o2&&o3)) return false;
  long rawT = z0 + z180;
  dicke  = DIM_SIGN * (twoC - rawT)      * MM_PRO_COUNT;   // 0+180 (versatz-frei)
  breite = DIM_SIGN * (twoC - 2L*z90)    * MM_PRO_COUNT + breiteOff;  // 'w'-kalibriert
#endif
  servoZu(SERVO_0); dreher.detach();
  if (dicke<0)  dicke=-dicke;
  if (breite<0) breite=-breite;
  return true;
}

// ---------- MESSEN mit Statistik ----------
void messen(float &dMw,float &dSd,float &bMw,float &bSd,int &ok){
  float ds[MAX_PASSES], bs[MAX_PASSES]; ok=0;
  for(int p=0;p<nPasses;p++){ float d,b; if(einPass(d,b)){ds[ok]=d;bs[ok]=b;ok++;} }
  dMw=dSd=bMw=bSd=0; if(!ok) return;
  for(int i=0;i<ok;i++){dMw+=ds[i];bMw+=bs[i];} dMw/=ok;bMw/=ok;
  for(int i=0;i<ok;i++){dSd+=sq(ds[i]-dMw);bSd+=sq(bs[i]-bMw);}
  dSd=sqrt(dSd/ok); bSd=sqrt(bSd/ok);
}

// ---------- KALIBRIERUNG 2C ----------
// Endmass bekannter Dicke einspannen. 2C so setzen, dass |2C-rawT|*k = KNOWN_GAUGE.
void kalibriere(){
  bool o1,o2; long z0=messePos(SERVO_0,o1); long z180=messePos(SERVO_180,o2);
  servoZu(SERVO_0); dreher.detach();
  if(!(o1&&o2)){ Serial.println(F("Kalibrieren fehlgeschlagen (kein Kontakt).")); return; }
  long rawT = z0+z180;
  twoC = rawT + (long)(DIM_SIGN * KNOWN_GAUGE / MM_PRO_COUNT);
  EEPROM.update(EE_MAGIC_ADDR, EE_MAGIC); EEPROM.put(EE_2C_ADDR, twoC);
  Serial.print(F("Kalibriert. 2C=")); Serial.println(twoC);
}

// Breite kalibrieren: Endmass bekannter Breite (KNOWN_BREITE) einspannen -> 'w'.
// Kompensiert den konstanten Versatz der Klemmung (Klemmschraube muss dabei
// genauso angezogen sein wie bei echten Messungen!).
void kalibriereBreite(){
  if(twoC==0){ Serial.println(F("Erst 'k' kalibrieren.")); return; }
  float dMw,dSd,bMw,bSd; int ok; messen(dMw,dSd,bMw,bSd,ok);
  if(!ok){ Serial.println(F("Breiten-Kalibrierung fehlgeschlagen.")); return; }
  breiteOff += (KNOWN_BREITE - bMw);
  EEPROM.put(EE_BOFF_ADDR, breiteOff);
  Serial.print(F("Breite kalibriert. Offset=")); Serial.println(breiteOff,4);
}

void setup(){
  Serial.begin(9600);
  pinMode(encoderA,INPUT_PULLUP); pinMode(encoderB,INPUT_PULLUP);
  pinMode(TASTER,INPUT_PULLUP);
  letzterZustand=(digitalRead(encoderA)<<1)|digitalRead(encoderB);
  attachInterrupt(digitalPinToInterrupt(encoderA),encoderUpdate,CHANGE);
  attachInterrupt(digitalPinToInterrupt(encoderB),encoderUpdate,CHANGE);
  dreher.attach(SERVO_PIN); dreher.writeMicroseconds(SERVO_0);
  motoren.enableDrivers(); stop();
  if(EEPROM.read(EE_MAGIC_ADDR)==EE_MAGIC){ EEPROM.get(EE_2C_ADDR,twoC); EEPROM.get(EE_BOFF_ADDR,breiteOff); }
  Serial.println(F("Bereit (v5 Kontakt-Mikrometer). '?' = Hilfe."));
  if(twoC==0) Serial.println(F("WARNUNG: unkalibriert -> 'k' (Dicke) + 'w' (Breite)."));
}

void loop(){
  if(!Serial.available()) return;
  char c=Serial.read();
  if(c=='m'){
    if(twoC==0){ Serial.println(F("Erst 'k' kalibrieren.")); return; }
    Serial.println(F("--- Messung ---"));
    float dMw,dSd,bMw,bSd; int ok; messen(dMw,dSd,bMw,bSd,ok);
    if(!ok){ Serial.println(F("Keine gueltige Messung.")); return; }
    Serial.print(F("DICKE:  ")); Serial.print(dMw,3); Serial.print(F(" +/- ")); Serial.print(dSd,3); Serial.println(F(" mm"));
    Serial.print(F("BREITE: ")); Serial.print(bMw,3); Serial.print(F(" +/- ")); Serial.print(bSd,3); Serial.println(F(" mm"));
    Serial.print(F("(")); Serial.print(ok); Serial.print('/'); Serial.print(nPasses); Serial.println(F(" Paesse)"));
  }
  else if(c>='1' && c<='9'){
    nPasses = c - '0';
    Serial.print(F("Durchlaeufe pro Messung: ")); Serial.print(nPasses);
    Serial.print(F("  (~")); Serial.print(nPasses*40); Serial.println(F(" s pro 'm')"));
  }
  else if(c=='k'){ kalibriere(); }
  else if(c=='w'){ kalibriereBreite(); }
  else if(c=='t'){ bool o; long p=tasteGemittelt(o); Serial.print(F("Kontakt @ ")); Serial.print(p); Serial.println(o?F(" ok"):F(" FEHLER")); }
  else if(c=='s'){
    int arr[4]={SERVO_0,SERVO_90,SERVO_180,SERVO_270};
    int n = USE_270_SERVO?4:3;
    for(int i=0;i<n;i++){ servoZu(arr[i]); Serial.print(F("Servo ")); Serial.println(arr[i]); delay(800); }
    servoZu(SERVO_0); dreher.detach();
  }
  else if(c=='?'){
    Serial.println(F("m=messen k=Dicke-Kal w=Breite-Kal t=antasten s=servo-test 1..9=Durchlaeufe"));
    Serial.print(F("2C=")); Serial.print(twoC);
    Serial.print(F("  breiteOff=")); Serial.print(breiteOff,4);
    Serial.print(F("  Durchlaeufe=")); Serial.print(nPasses);
    Serial.print(F("  270-Servo=")); Serial.println(USE_270_SERVO);
  }
}

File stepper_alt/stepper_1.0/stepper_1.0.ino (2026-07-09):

// ============================================================
//  Stepper Motor - Allgemeine Zyklus-Steuerung
//  Plattform : Arduino (Uno / Nano / Mega)
//
//  Unterstuetzte Treiber-Modi:
//    STEP_DIR   -> A4988, DRV8825, TMC2208  (2-Pin)
//    VIER_DRAHT -> ULN2003, L298N, L293D    (4-Pin)
// ============================================================

#include <Stepper.h>

// ── Treiber-Modus Konstanten (NICHT veraendern) ──────────────
#define STEP_DIR    1
#define VIER_DRAHT  2

// ── Treiber-Modus waehlen ───────────────────────────────────
#define TREIBER_MODUS  STEP_DIR   // <-- hier aendern

// ── Gemeinsame Parameter ────────────────────────────────────
#define SCHRITTE_PRO_UMDREHUNG  200   // Vollschritt = 200
#define PAUSEN_MS               300   // Pause zwischen Phasen (ms)

// ── STEP_DIR Parameter ──────────────────────────────────────
#if TREIBER_MODUS == STEP_DIR
  #define STEP_PIN          3
  #define DIR_PIN           4
  #define ENA_PIN           5     // auf 255 setzen wenn nicht verwendet
  #define SCHRITT_DELAY_US  1000  // Puls-Breite in Mikrosekunden
#endif

// ── VIER_DRAHT Parameter ────────────────────────────────────
#if TREIBER_MODUS == VIER_DRAHT
  #define IN1 8
  #define IN2 9
  #define IN3 10
  #define IN4 11
  #define UMDREHUNGEN_PRO_MIN 15
#endif

// ============================================================
//  ZYKLUS-DEFINITION
//  { Schritte, Richtung }   Richtung: +1 vorwaerts, -1 rueckwaerts
// ============================================================
struct Phase {
  uint16_t schritte;
  int8_t   richtung;
};

const Phase ZYKLUS[] = {
  { 400, +1 },   // Phase 1 - 2 Umdrehungen vorwaerts
  { 200, -1 },   // Phase 2 - 1 Umdrehung rueckwaerts
  { 100, +1 },   // Phase 3 - 0.5 Umdrehung vorwaerts
  { 300, -1 },   // Phase 4 - 1.5 Umdrehungen rueckwaerts
};

const uint8_t ANZAHL_PHASEN = sizeof(ZYKLUS) / sizeof(ZYKLUS[0]);

// ============================================================
//  INTERNE VARIABLEN
// ============================================================
#if TREIBER_MODUS == VIER_DRAHT
  Stepper motor(SCHRITTE_PRO_UMDREHUNG, IN1, IN3, IN2, IN4);
#endif

struct Protokolleintrag {
  uint16_t schritte;
  int8_t   richtung;
};

Protokolleintrag protokoll[8];  // max. 8 Phasen

// ============================================================
//  TREIBER-ABSTRAKTION
// ============================================================

void motorSetup() {
#if TREIBER_MODUS == STEP_DIR
  pinMode(STEP_PIN, OUTPUT);
  pinMode(DIR_PIN,  OUTPUT);
  #if ENA_PIN != 255
    pinMode(ENA_PIN, OUTPUT);
    digitalWrite(ENA_PIN, LOW);  // LOW = aktiv beim A4988
  #endif
#endif
#if TREIBER_MODUS == VIER_DRAHT
  motor.setSpeed(UMDREHUNGEN_PRO_MIN);
#endif
}

void motorDeaktivieren() {
#if TREIBER_MODUS == STEP_DIR
  #if ENA_PIN != 255
    digitalWrite(ENA_PIN, HIGH);
  #endif
#endif
#if TREIBER_MODUS == VIER_DRAHT
  digitalWrite(IN1, LOW); digitalWrite(IN2, LOW);
  digitalWrite(IN3, LOW); digitalWrite(IN4, LOW);
#endif
}

void schritteAusfuehren(uint16_t anzahl, int8_t richtung) {
#if TREIBER_MODUS == STEP_DIR
  digitalWrite(DIR_PIN, richtung > 0 ? HIGH : LOW);
  delayMicroseconds(2);
  for (uint16_t i = 0; i < anzahl; i++) {
    digitalWrite(STEP_PIN, HIGH);
    delayMicroseconds(SCHRITT_DELAY_US);
    digitalWrite(STEP_PIN, LOW);
    delayMicroseconds(SCHRITT_DELAY_US);
  }
#endif
#if TREIBER_MODUS == VIER_DRAHT
  motor.step((int32_t)anzahl * richtung);
#endif
}

// ============================================================
//  PROTOKOLL-AUSGABE
// ============================================================

void protokollAusgeben() {
  int32_t  netto   = 0;
  uint32_t gesamt  = 0;

  Serial.println();
  Serial.println(F("===================================="));
  Serial.println(F(" SCHRITT-PROTOKOLL - ZYKLUS ENDE   "));
  Serial.println(F("===================================="));

  for (uint8_t i = 0; i < ANZAHL_PHASEN; i++) {
    Serial.print(F("Phase "));
    Serial.print(i + 1);
    Serial.print(F(": "));
    Serial.print(protokoll[i].schritte);
    Serial.print(F(" Schritte  ->  "));
    Serial.println(protokoll[i].richtung > 0 ? F("VORWAERTS") : F("RUECKWAERTS"));

    gesamt += protokoll[i].schritte;
    netto  += (int32_t)protokoll[i].schritte * protokoll[i].richtung;
  }

  Serial.println(F("------------------------------------"));
  Serial.print(F("Gesamt     : "));
  Serial.print(gesamt);
  Serial.println(F(" Schritte"));

  Serial.print(F("Netto-Pos. : "));
  if (netto >= 0) Serial.print('+');
  Serial.print(netto);
  Serial.print(F(" Schritte ("));
  Serial.print((float)netto / SCHRITTE_PRO_UMDREHUNG, 2);
  Serial.println(F(" Umdrehungen)"));

  Serial.println(F("------------------------------------"));
#if TREIBER_MODUS == STEP_DIR
  Serial.println(F("Treiber : STEP/DIR"));
#else
  Serial.println(F("Treiber : 4-Draht"));
#endif
  Serial.println(F("===================================="));
  Serial.println();
  Serial.println(F(">> 'r' senden = erneut starten"));
}

// ============================================================
//  ZYKLUS
// ============================================================

void zyklusStarten() {
  Serial.println(F("Zyklus laeuft ..."));
  Serial.println();

  for (uint8_t i = 0; i < ANZAHL_PHASEN; i++) {
    Serial.print(F("  Phase "));
    Serial.print(i + 1);
    Serial.print(F("/"));
    Serial.print(ANZAHL_PHASEN);
    Serial.print(F(" ... "));

    schritteAusfuehren(ZYKLUS[i].schritte, ZYKLUS[i].richtung);
    protokoll[i] = { ZYKLUS[i].schritte, ZYKLUS[i].richtung };

    Serial.println(F("OK"));
    delay(PAUSEN_MS);
  }

  motorDeaktivieren();
  protokollAusgeben();
}

// ============================================================
//  SETUP & LOOP
// ============================================================

void setup() {
  Serial.begin(9600);
  motorSetup();

  delay(2000);  // Zeit zum Oeffnen des Serial Monitors

  Serial.println(F("====================================="));
  Serial.println(F("  Stepper Motor - Zyklus-Steuerung   "));
  Serial.println(F("====================================="));
  Serial.println();

  zyklusStarten();
}

void loop() {
  if (Serial.available() > 0) {
    char c = Serial.read();
    if (c == 'r' || c == 'R') {
      Serial.println(F("Neustart..."));
      motorSetup();
      zyklusStarten();
    }
  }
}

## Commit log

2026-07-09 Messstand v5: Kontakt-Mikrometer (Teile, Baugruppe, Firmware, Doku)
    - 12 Druckteile (STL+IPT) inkl. Schutz (Kopfbruecke, Fensterdeckel)
    - Messstand_v4.iam Baugruppe mit 23 Komponenten, eingefaerbt
    - Firmware v5: Antasten, Servo+Rastbolzen, k/w-Kalibrierung, T8x2
    - Bausatz-Anleitung mit Amazon-Bestellliste (~78 EUR)
    [12x6_Probestück.ipt, 12x6_Probestück.stl, Aluprofil_20x20_H100.ipt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]
2026-07-09 Kompatibilitaets-Fixes fuer gekaufte Teile
    - Schalter-Boss (beide Schlitten): V-153-Mikroschalter (27.8mm,
    Lochabstand 22.2) statt KW12; M3-Langloecher, Flaeche bei y=17.5
    (Stift-Bahn frei), hoehenverstellbar fuer Hebel-Justage
    - Motorblock: 4 radiale Langloecher statt fester Bohrungen
    (N20-Bohrbilder variieren 8..9.5mm)
    [Dreh_Klemme.ipt, Grundplatte_v4.ipt, Idler_Klemme.ipt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]
2026-07-09 Durchlaeufe zur Laufzeit waehlbar ('1'..'9'), Default 3
    Jeder Durchlauf rastet den Winkel neu ein -> mittelt Schalter- und
    Rastfehler mit 1/sqrt(n). Ausgabe Mittelwert +/- Stdabw ueber Durchlaeufe.
2026-07-09 Messzeit optimiert: kurzer Zwischen-Rueckzug (1.5mm), Anfahrt 180
    3 Durchlaeufe bleiben Default (Sweet Spot ±15µm) — Messung jetzt
    ~3 min statt ~4.5 min ohne Genauigkeitsverlust (Feinantastung
    unveraendert langsam, voller 5mm-Rueckzug nur vor dem Drehen).
2026-07-09 Zielzeit ~40s pro Messung: 1 Durchlauf Default, Anfahrt 250, Backoff 0.5, Zwischen-Rueckzug 1.0, Servo-Settle 400/250ms
    Feinantastung unveraendert (SPEED_SLOW 45) — Genauigkeit bleibt.
    '3' im Serial Monitor = Praezisionsmodus (~2 min, 1/sqrt(n)).
2026-07-10 Repo uebersichtlich strukturiert: cad/ stl/ gesliced/ firmware/ scripts/ docs/ archiv/
    - Aktive Teile+Baugruppe in cad/, Druck-STLs in stl/, H2C-Platten in gesliced/
    - Build-Skripte in scripts/ (Ausgabepfade auf ../cad + ../stl umgestellt,
    Pipeline nach Umbau verifiziert), Altes in scripts/archiv/ + archiv/
    - README komplett neu (v5-Konzept, Struktur, Inbetriebnahme)
    [12x6_Probestück.ipt, 12x6_Probestück.stl, Alles_Eine_Platte.gcode.3mf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]
2026-07-12 FIX: Wellen-Bohrungen in Grundplatten-Bossen fehlten im Modell!
    Blind-Bohrung von der Boss-Oberseite (kNeg) UND kSym-Schnitt versagten
    still — einzig zuverlaessig: Bohrung als Innenkontur direkt im
    Boss-Join-Sketch (Rohr-Extrusion). Volumen-Beweis: -1,53 cm3 = exakt
    2x D7.8x16. Taststift-Loch war vorhanden (im Druck nur zugeschmolzen).
    Platte_1 + Alles_Eine_Platte neu gesliced.
    [Alles_Eine_Platte.gcode.3mf, Dreh_Klemme.ipt, Grundplatte_v4.ipt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]
2026-07-13 Farbige Explosions-Montagebilder (Servo-Seite, Schlitten, Taststift-Kette)
    [Feder_ph.ipt, LM8UU_ph.ipt]
2026-07-13 FIX: Mikroschalter-Langloecher am Schlitten-Boss fehlten komplett!
    Root Cause: nachtraeglicher Schnitt in einen separat gejointen Boss
    versagt bei diesem Inventor/COM-Setup KOMPLETT still - getestet mit
    XZ/XY-Ebenen, kPos/kNeg/kSym, sogar uebergrossem Testschlitz der jede
    Achsen-Interpretation abdeckt. Profiles.Count als Diagnose ist ebenfalls
    unzuverlaessig (zeigt auch bei garantiert funktionierenden Standard-Joins 0).
    Fix: Boss in 3 gestapelte XY-Ebenen-Join-Schichten zerlegt, mittlere
    Schicht hat die Langloecher als 3 Segment-Rechtecke statt 1 Vollrechteck
    - reine XY+kJoin-Technik, die im ganzen Projekt nie versagt hat.
    Betraf Taster_Schlitten UND Taster_Schlitten_M8. Volumen-Beweis:
    59.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
    [Alles_Eine_Platte.gcode.3mf, Dreh_Klemme.ipt, Grundplatte_v4.ipt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]
